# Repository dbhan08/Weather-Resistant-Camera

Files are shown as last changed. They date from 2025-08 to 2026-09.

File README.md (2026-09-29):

# Weather-Resistant Camera

An STM32-based enclosure that keeps a camera lens usable in rain and frost.
A vision model on the host PC (or, with the TFLite Micro path, on the MCU)
detects water on the lens and triggers a servo wiper; an on-die thermistor
turns a heating pad on below a threshold.  UIUC ECE 445 senior design,
Spring 2025.

## Run it

```bash
# firmware: open Final.ioc in STM32CubeIDE, build main.c, flash the Nucleo-F4
# vision (original OpenCV heuristic):
python final_code.py               # webcam -> HSV mask -> % coverage -> "START" over serial
# vision (CNN, see CNN/README.md):
python -m lens_soiling.infer runs/procedural/soilnet.pt --camera 1 --port COM3
```

## How it works

- **Firmware (`main.c`).**  TIM2 PWM drives the servo; `Set_Servo_Angle`
  maps 0–180° to a 210–1050 tick pulse.  ADC1 reads the internal temperature
  sensor with the factory `TS_CAL1/2` calibration, and drives a MOSFET on PA5
  to switch the heater.  USART2 at 115200 baud accepts 5-byte commands
  (`START`, `STOPP`) from the PC; `START` sweeps the wiper 60→115→60°.
- **Vision, heuristic (`final_code.py`).**  HSV threshold on low saturation
  and high value, morphological close, contours, enclosing circles, then
  percent of masked pixels.  Over 5 % sends `START`.
- **Vision, CNN (`CNN/`).**  Tile-level classifier: a ported pretrained
  raindrop CNN distilled into a ~20 k-parameter int8 model for TFLite Micro,
  plus a tested PyTorch fallback trained on synthetic drops and frost.
- **Hardware.**  KiCad PCB (`PCB Design*/`), 5 V and 3.3 V regulators, MOSFET
  heater switch, logic-level shifter, servo header.  Demo ran on the Nucleo
  dev board after the second PCB's MCU was damaged during hand soldering.

## Layout

```
main.c, Final.ioc          STM32 firmware and CubeMX project
final_code.py              OpenCV heuristic + serial trigger (PC)
python_to_stm_comm.py      serial protocol smoke test
CNN/                       CNN detection: pretrained port + from-scratch pipeline
Servo Motor code/, Temperature sensor code/   subsystem test firmware
PCB Design*/               KiCad
Lab Notebooks/             per-member design logs
```

## Stack

C (STM32 HAL), Python, OpenCV, PyTorch, TensorFlow Lite Micro, KiCad.

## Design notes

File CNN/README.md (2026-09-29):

# Rain detection CNN for the camera lens

The vision subsystem is a tile-level raindrop classifier that runs on the
STM32 under TensorFlow Lite Micro.  The MCU captures a 160x120 frame over
DCMI, classifies each 48 px tile with an int8 CNN, and triggers the wiper
when the fraction of raindrop tiles passes 5 %.  It replaces the PC-side HSV
threshold + contour heuristic in `../final_code.py`, which false-fired on
glare and surface texture (lab notebook, 2025-03-07 and 2025-04-05).

| Path | Folder | What it is |
|---|---|---|
| **Deployed** | `pretrained/` + `pretrained/tflm/` | Breckon's AlexNet-30² raindrop weights (ICIP 2018) → Keras port → fine-tune → distilled 20 k-param student → full-int8 TFLite → C array → TFLite Micro firmware |
| Fallback / experiments | `lens_soiling/` | PyTorch net trained on synthetic drops and frost; `pytest tests` passes |

## Pretrained path: how it works

1. **Port the weights (`port_breckon.py`).**  The published model is a
   TFLearn checkpoint from TensorFlow 1.x.  TF1 and TFLearn do not install on
   current Python or Apple Silicon, and the TFLite converter cannot read a
   `.tfl`.  But TF2's `tf.train.load_checkpoint` still reads TF1 variables,
   so the script rebuilds the exact graph in Keras and copies each tensor
   by name (`Conv2D`, `Conv2D_1`, ... `FullyConnected_2`).  Every shape is
   asserted, and the repo's 16 sample patches are re-classified so the port
   can be checked before anything else runs.
   Architecture: five convs (96·11×11/4, 256·5×5, 384·3×3, 384·3×3,
   256·3×3) with 3×3/2 max-pools and local response normalization, then
   4096-tanh, 4096-tanh, 2-softmax.  Input is a 30×30 RGB patch scaled to
   [0, 1].  The paper reports 0.95 accuracy on windshield-camera patches.
2. **Get labelled patches (`data_windshield.py`).**  RaindropsOnWindshield
   (8,190 frames, 3,390 with drops, pixel masks, CC BY 4.0) is cut into
   30×30 patches: positive if the mask covers ≥ 30 % of the patch, negative
   only if the patch *and a one-patch margin* are mask-free.  Splits are by
   video sequence so frames from one clip never leak across train / test.
3. **Fine-tune (`finetune.py`).**  Breckon's camera looked through a
   windshield.  Ours sits millimetres from the drops, so drops are bigger and
   blurrier.  Standard two-stage transfer: head only at lr 1e-3, then all
   layers at 1e-5 with early stopping.  Flips and ±45° rotation, as in the
   paper.
4. **Distill to an MCU-sized student (`distill_student.py`).**  After three
   pools a 30×30 input is 1×1×256, then 256×4096 and 4096×4096 dense layers:
   about 18 M parameters, 75 MB fp32, 19 MB int8.  The STM32F4 Nucleo has
   512 KB flash and 192 KB SRAM, and TFLite Micro has no LRN kernel.  So the
   teacher stays on the PC and a 48×48 depthwise-separable student
   (~20 k params, only CONV_2D / DEPTHWISE_CONV_2D / MEAN / FULLY_CONNECTED)
   is trained on the teacher's softened probabilities (Hinton et al. 2015,
   T = 4, α = 0.7) plus the hard labels.
5. **Quantize and emit C (`to_tflite.py`).**  Full-integer int8 with a
   representative dataset of validation patches, int8 in/out, then a
   `g_raindrop_student[]` C array.  The report records op list, byte size, input
   scale/zero-point, and int8-vs-fp32 argmax agreement.
6. **Run on the board (`tflm/`).**  `raindrop_inference.cc` sets up
   `MicroInterpreter` with a six-op resolver and a 48 KB arena, quantizes
   each tile with the converter's scale/zero-point, and returns the fraction
   of tiles classed raindrop.  `main_hook.c` shows the change to `main.c`:
   the servo sweep triggers on coverage ≥ 5 % with a 4 s cooldown instead
   of on a UART `START`.

```bash
# in a venv with tensorflow>=2.10, pillow, numpy
bash raindrop-detection-cnn/download-models.sh            # Breckon weights (MIT)
python -m pretrained.port_breckon models/alexnet_30_2_classification.tfl --out runs/breckon --samples raindrop-detection-cnn/images/classification
zenodo_get https://zenodo.org/record/4680442 --output-dir data/RaindropsOnWindshield
python -m pretrained.data_windshield data/RaindropsOnWindshield --out data/patches
python -m pretrained.finetune runs/breckon/alexnet30_2.keras data/patches --out runs/breckon_ft
python -m pretrained.distill_student runs/breckon_ft/alexnet30_2_ft.keras data/patches --out runs/student
python -m pretrained.to_tflite runs/student/student.keras data/patches/val --out runs/tflite --name raindrop_student
```

### Why not ship the pretrained model as-is

- It is 18 M parameters.  Too big for any STM32 by two orders of magnitude.
- It uses LRN, which TFLite Micro does not implement.
- It was trained on a windshield view, not a lens millimetres from the water.
- It has no ice class.  Ice is left to the thermistor, which the firmware
  already does.  A frost class can be added to the student later from the
  synthetic frost renderer in `lens_soiling/synth.py` or from real frames.

## From-scratch path (tested)

`lens_soiling/` is a PyTorch pipeline that renders adherent drops (minified,
inverted, blurred scene with a dark rim and specular highlight) and frost
(blur, desaturation, lift to white, fractal crystal texture) onto clean
tiles, trains a 19.7 k-parameter net, quantizes it to int8 and dumps a C
weight header.  On procedural backgrounds it reaches 98.5 % validation
accuracy with 100 % int8/fp32 argmax agreement.  That number is synthetic
and must not be quoted as real-world accuracy.

```bash
pip install -r requirements.txt
python -m pytest tests -q
python -m lens_soiling.train --epochs 8 --out runs/procedural
python -m lens_soiling.export runs/procedural/soilnet.pt --out runs/procedural
python -m lens_soiling.infer runs/procedural/soilnet.pt --image test.jpg
```

## Firmware

`pretrained/tflm/` holds the on-MCU side: `raindrop_inference.cc` (TFLM
interpreter, 6-op resolver, 48 KB arena, per-tile int8 quantization, DWT
cycle timing), `camera_dcmi.c` (OV7670 QQVGA RGB565 over DCMI + DMA),
and `main_raindrop.c`, the full main loop: thermistor → heater MOSFET,
capture → CNN → coverage → servo sweep, one status line per second over
USART2 with coverage, tile grid and inference microseconds.  Build steps
and the SRAM budget are in `pretrained/tflm/README.md`.

## Numbers

Record them from the USART2 status line (`nn_us`, `cover`, `grid`) and
from `export_report.json` / `tflite_report.json`.  Fill this table from
your own logs; do not copy synthetic numbers here.

| Metric | Value | Source |
|---|---|---|
| Student params / int8 model bytes | | `tflite_report.json` |
| int8 vs fp32 argmax agreement | | `tflite_report.json` |
| Test accuracy on held-out lens patches | | `distill_report.json` |
| On-MCU latency per 3x2 tile frame | | `nn_us` in the USART2 log |
| Tensor arena used | | `arena_used_bytes()` |

## References

- Guo, Akcay, Adey, Breckon. *On the impact of varying region proposal strategies for raindrop detection and classification using CNNs.* ICIP 2018. Code + weights: https://github.com/tobybreckon/raindrop-detection-cnn
- Soboleva, Shipitko. *Raindrops on Windshield: Dataset and Lightweight Gradient-Based Detection Algorithm.* 2021. https://github.com/EvoCargo/RaindropsOnWindshield
- Uřičář et al. *SoilingNet*, ITSC 2019; Das et al. *TiledSoilingNet*, 2020 (tile-level coverage idea).
- Qian et al. *Attentive GAN for Raindrop Removal*, CVPR 2018; You et al. *Adherent Raindrop Modeling*, TPAMI 2016 (drop appearance model).
- Hinton, Vinyals, Dean. *Distilling the Knowledge in a Neural Network.* 2015.
- Howard et al. *MobileNets.* 2017.

## Stack

Python, TensorFlow / Keras, TensorFlow Lite Micro, PyTorch, NumPy, Pillow, pytest, C/C++ on STM32 HAL.

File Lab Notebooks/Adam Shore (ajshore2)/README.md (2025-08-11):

# 2025-02-12 - Project Proposal
After working on the project proposal, I believe we have a good idea. It is complex enough to challenge us, while also being within the scope of the class. Me and my group worked to complete our proposal this week. I was mostly responsible for the high-level requirements, visual aid, ethics, and safety sections. Beyond this, I helped contribute to each of the other sections as well. 

# 2025-02-18 - Discussion with Professor Fliflet
Professor Fliflet helped us brainstorm many other helpful ideas that will allow us to better complete our project. First, we will add in an LED to the heating system so it is easier for the user to identify when the heating component is activated. This also will make debugging easier. Additionally, we decided to not use hydrophobic spray. This would make our project much harder and put much more stress on the machine shop. This should allow us to better focus on our primary goals for the project.

# 2025-02-24 - Researching Parts
I have been looking into various different components to use for a variety of subsystems on the project. Primarily with the temperature sensor, it is difficult to find one that is easy to use and is waterproof (as to not break from rain). Temporarily I have settled on the temperature sensor listed below since it follows these requirements and appears to be user friendly.

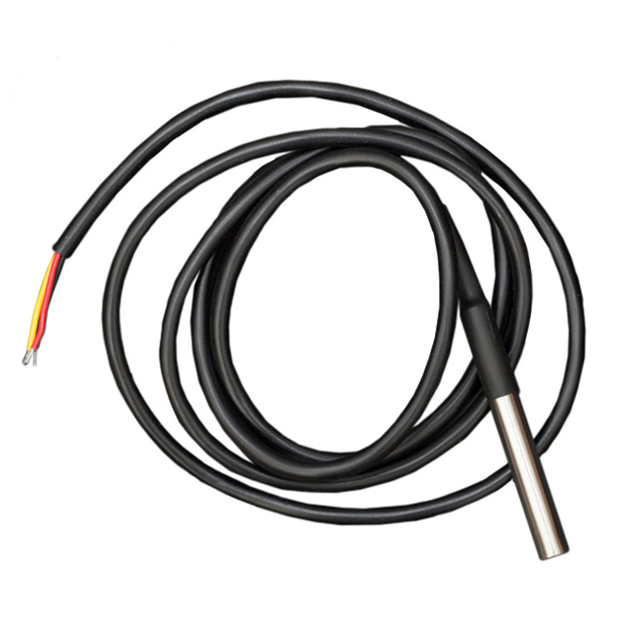
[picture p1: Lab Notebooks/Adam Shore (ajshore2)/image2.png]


[Link to Temperature Sensor](https://www.digikey.com/en/products/detail/dfrobot/DFR0198/7597054)

Additionally, we have been reviewing and evaluating which microcontroller is best suited for our project. We have temporarily decided to go with an STM32 microcontroller since it has many online resources to help us interact with it. Additionally, the ECE445 website has a wiki page which we find very helpful in learning about using this microcontroller. 

[Link to STM32 Microcontroller](https://www.digikey.com/en/products/detail/stmicroelectronics/STM32F103C8T6/1646338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)

After meeting with my team, we have also decided to not use any humidity sensor. We think it will be very difficult to incorporate this into our design since it would complicate the schematics greatly and possibly cause blockage of the camera. We will try to revisit this and add it to our project later if there is time at the end. However, we believe our project can still function effectively without this. 

# 2025-02-27 - First PCB
Since we do not think our first PCB is ready to order yet, we are going to spend more time on it and ensure it will work before ordering. This means we will be placing our first PCB order in the second-round orders. So far, we have constructed a PCB that has a majority of the components we need, however, we need to add any necessary resistors and capacitors for these components, as well as research any additional components we may need. 

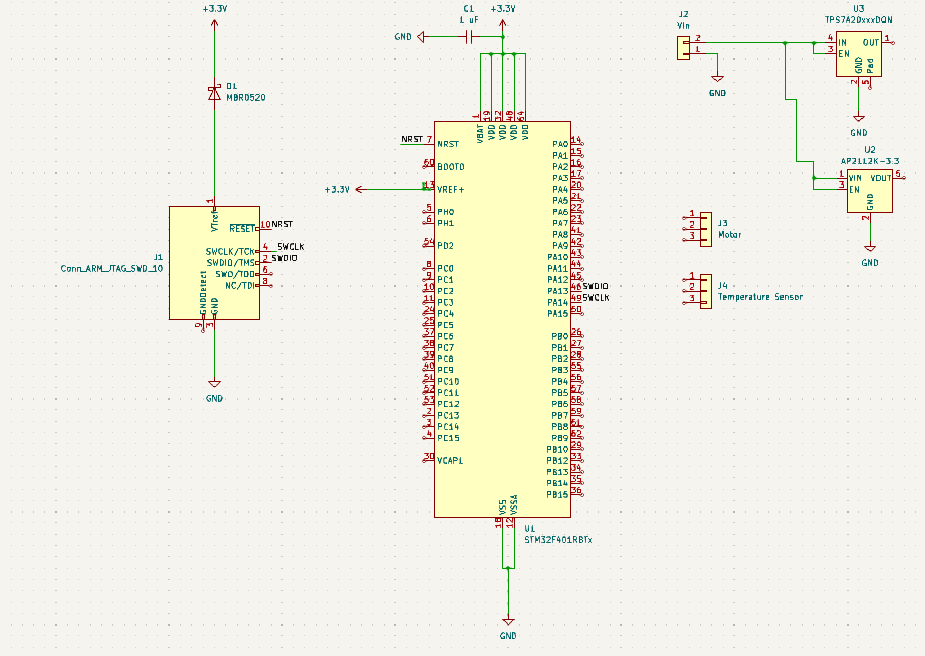
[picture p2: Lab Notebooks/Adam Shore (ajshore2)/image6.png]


# 2025-03-01 - First PCB (Continued)
We have added multiple other components to our PCB. This includes a receiver to communicate with the computer in the form of a USB-C 2.0 port. Additionally, we added a component to plug the heater into. Finally, we added another voltage regulator in order to power the heater, which we realized needs 5 V to power. 

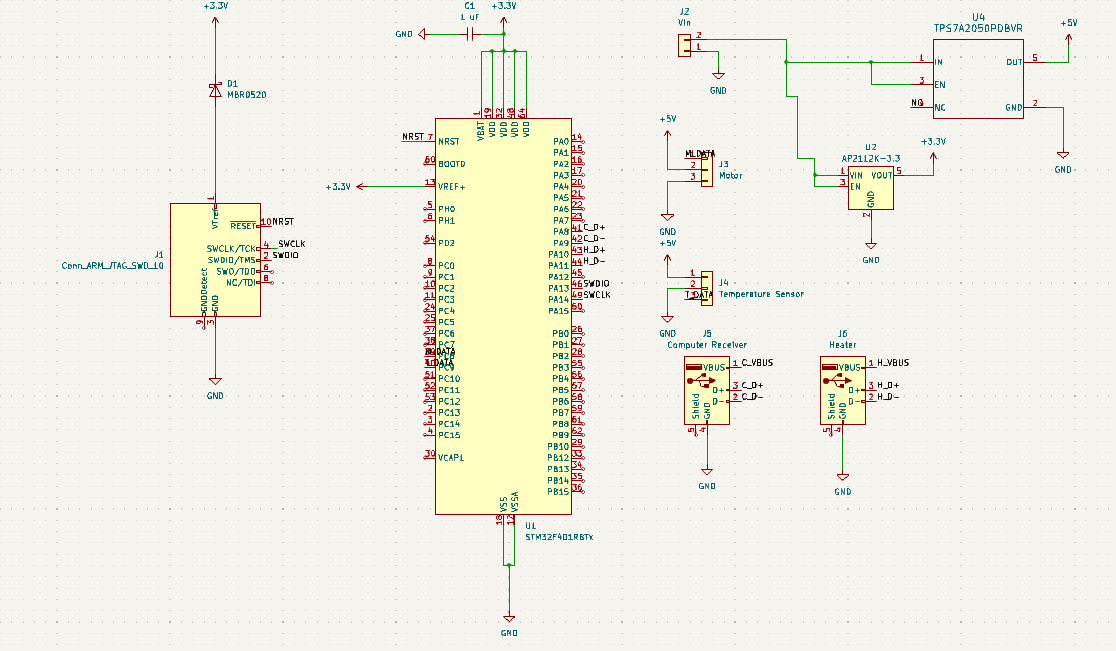
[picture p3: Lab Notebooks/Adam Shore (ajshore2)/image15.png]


# 2025-03-05 - Design Document
Me and my group spent lots of time working on our design document this week. We want to make sure we are thorough with our work so that we can effectively build and test our project later. While my group members and I all played a role in each section, I was primarily responsible for the following sections: cost, schedule, high-level-requirements, visual aid, ethics, safety, and citations. 

# 2025-03-06 - First PCB (Continued)
I have continued working on our PCB design and believe we are now at a point where we can place our order. We have added a MOSFET which will allow for the heater to properly run. We have also added a spot for the LED light, the debug header, the timing crystals, and more. Additionally, we added many more resistors and capacitors which we needed in our design.

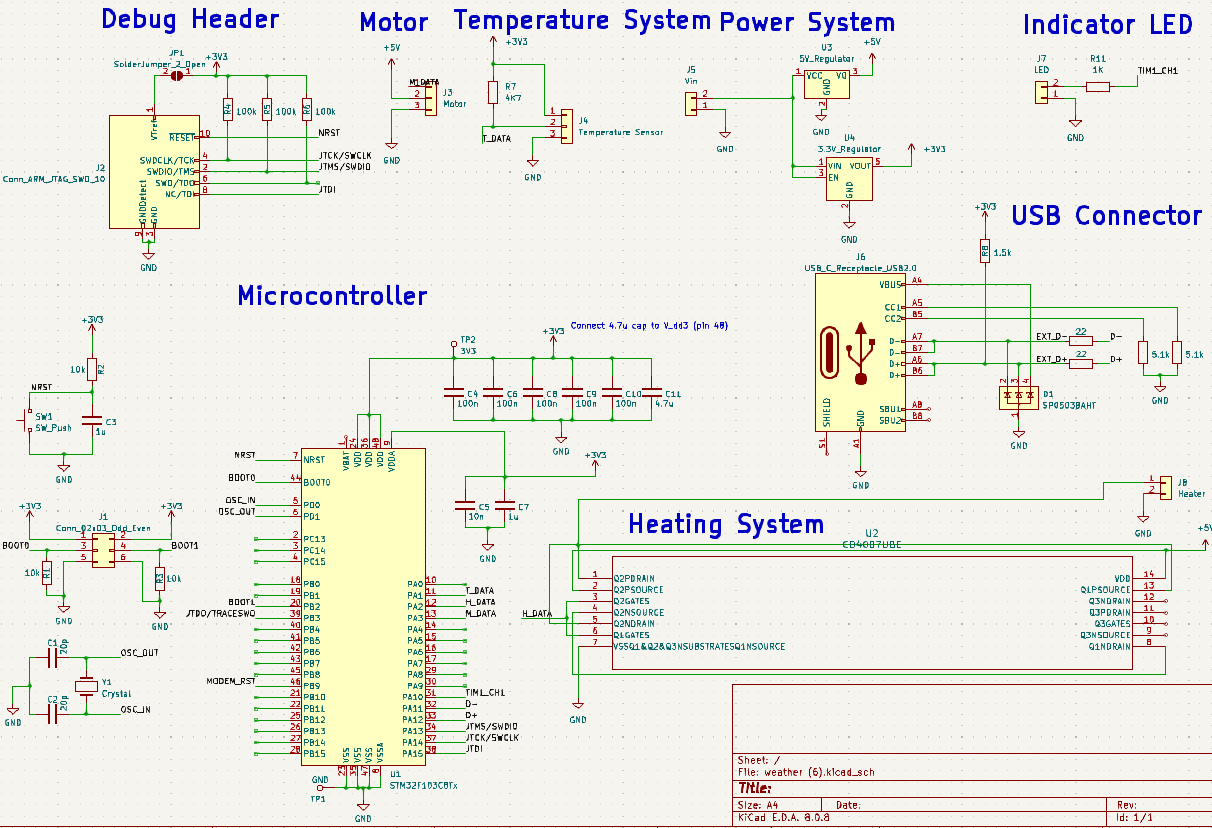
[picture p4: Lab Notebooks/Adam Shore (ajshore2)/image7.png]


# 2025-03-07 - Temperature Sensor Readings
I have been working with our temperature sensor (DFR0198) and our development board in order to try to get proper readings with the device. Unfortunately, I am continuously getting errors reading from the device. I am able to properly communicate a “reading” from the microcontroller to my computer for me to visualize using UART and displaying it with Putty. However, the readings are coming in as gibberish characters, meaning there is either a problem with the data line, the temperature sensor itself, or how I am reading it. 

# 2025-03-08 - Breadboard Assembly
My group has tried to begin assembling the parts together utilizing our development board, in order to have some subsystems working in time for the breadboard demo. Currently we plan to show the temperature sensor readings (even though they are incorrect), the PWM generation from our development board, and our CNN model. 

# 2025-03-13 - Temperature Sensor Readings (Continued)
Since I am unable to get proper readings using the DFR0198 temperature sensor, I have attempted to get readings using the on-board temperature sensor. This has worked and we will be using this method going forward. Once the PCB is working, I plan to revisit the temperature sensor issue and try once again to obtain correct readings. 

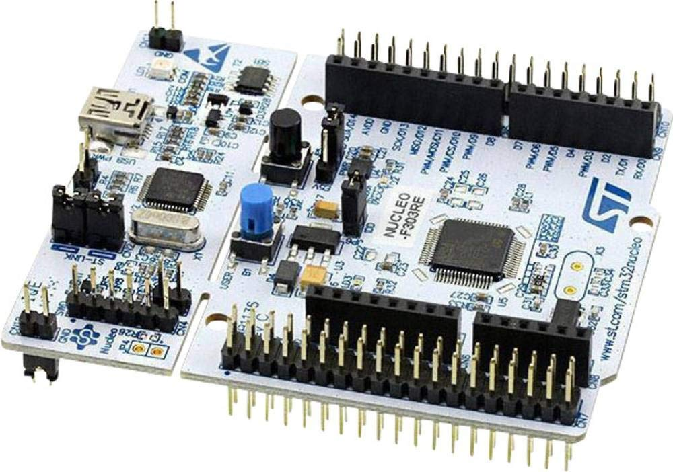
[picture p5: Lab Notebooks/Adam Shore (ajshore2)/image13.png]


[Link to STM32 Development Board & Image](https://www.amazon.com/Nucleo-64-development-STM32F303RE-supports-connectivity/dp/B01N6EKDEF)

In order to verify my results, I conducted 20 trials where I read the temperature from the development board and compared it to the actual temperature. I did this by testing a few various environments which slowly became colder. I waited for the temperature sensor to adjust and then compared this to the thermometer readings. After the following results, I concluded that it was accurate.

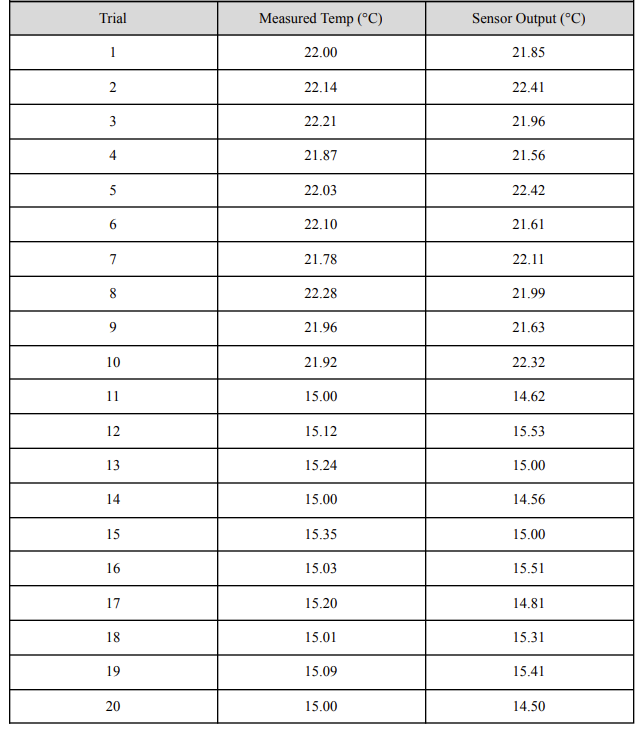
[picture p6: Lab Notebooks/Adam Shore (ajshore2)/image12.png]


# 2025-03-25 - First PCB Assembly
We have begun soldering our first PCB. We are attempting to solder it in subsystems in an attempt to unit test each subsystem. Some of our subsystems we have soldering and verified work, such as the power subsystem. We know certain parts of our PCB will not work because we realized mistakes we had made after ordering it. This came in various forms such as forgetting pull-up resistors in certain areas, utilizing the incorrect components, and more. Because of this, we were not able to solder and test everything. 

# 2025-04-03 - Second PCB
After noting errors that prevented us from being able to effectively assemble and test our PCB, we started creating our next PCB which revised these errors. We corrected the MOSFET circuit, the temperature sensor circuit, and more. We plan to finalize these changes and order the PCB as soon as possible. 

# 2025-04-08 - Breadboard Assembly
In case our PCB still fails we are attempting to assemble everything together utilizing the development board and a breadboard. I have begun programming the microcontroller to trigger the heater and motor based on the temperature sensor readings. I am also practicing various ways to use python to trigger a high pin output on the board. This is important because we need the OpenCV model to be able to trigger the motor physically. I am attempting to do this communication through UART and the TX/RX pins. Below is the microcontroller code I have so far in order for the temperature to trigger the heater:

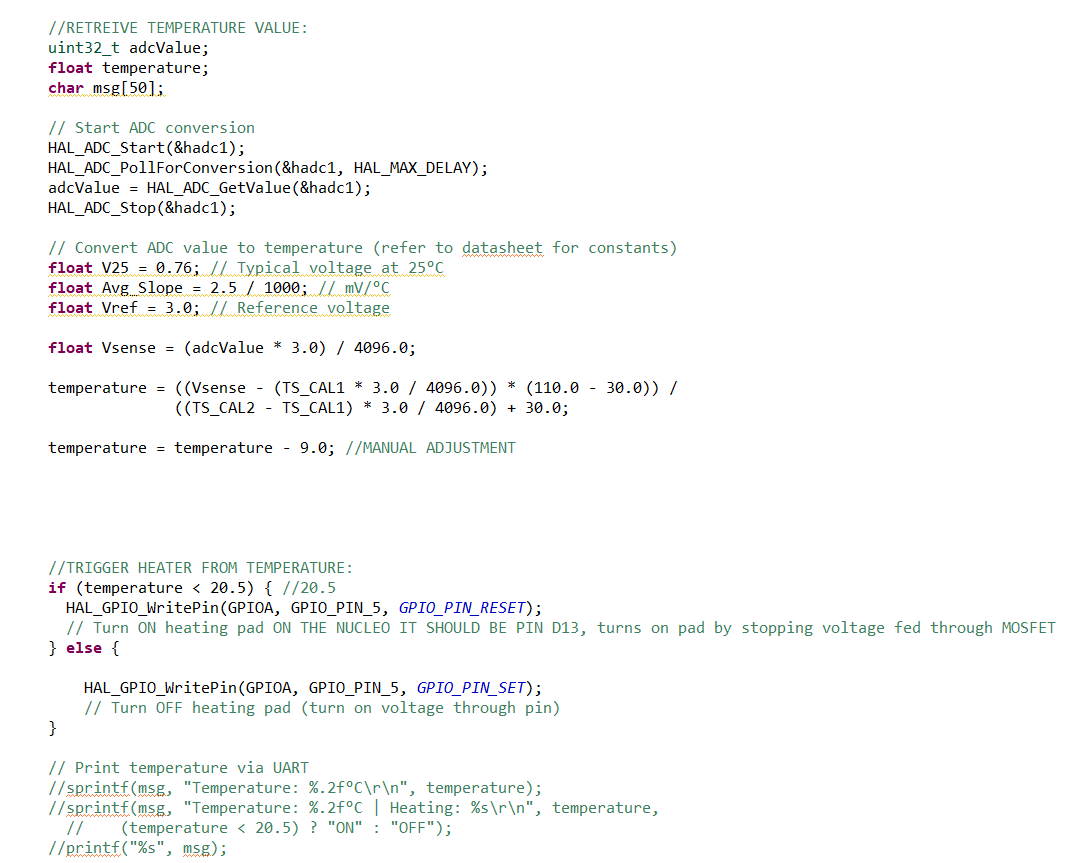
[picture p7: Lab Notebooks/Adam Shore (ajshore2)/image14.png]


# 2025-04-10 - Breadboard Assembly (Continued)
I have been able to find a way to communicate from Python to the Development board in order to have the OpenCV model directly trigger the motor. Here is the code I am using to do this: 

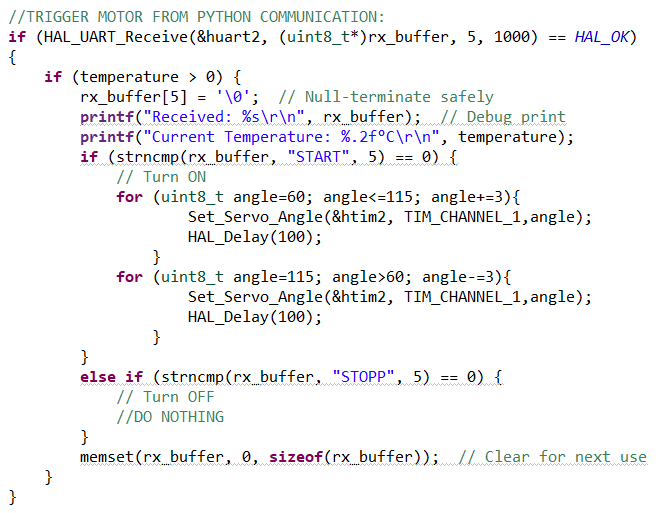
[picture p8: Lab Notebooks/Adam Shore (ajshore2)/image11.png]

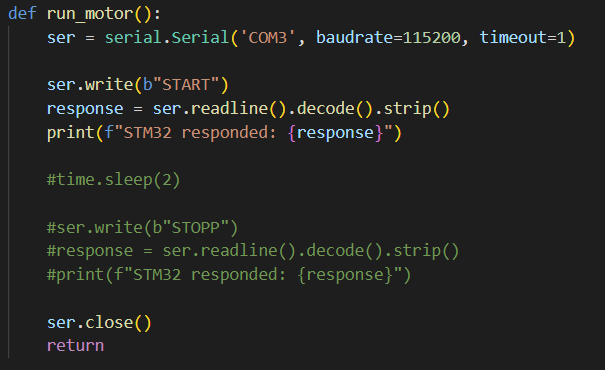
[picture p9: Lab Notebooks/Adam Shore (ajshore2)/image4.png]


# 2025-04-23 - Second PCB Assembly
When assembling our second PCB, we broke our microcontroller. Unfortunately, we were not able to solder the microcontroller due to the intricacies of its parts. We are going to try and order another one in time and attempt to solder it again, however, we are also going to shift our focus to making sure our final project works on the development board in order to ensure we have a final working product.

# 2025-04-25 - Final Demo Preparation
My group now has our final project working on our development board. We are able to trigger various subsystems from other subsystems. We are now going to start practicing what we want to show for our final demo so that we are prepared to showcase both our end-to-end functionality along with our subsystems verifications. We are using a cooler filled with ice in order to imitate a freezing environment, however, this does not replicate a perfect freezing temperature. In order to adjust for this, we will simulate our conditions where 20 degrees Celsius is our threshold for freezing, instead of 0 degrees Celsius. Below is our final layout of our microcontroller:

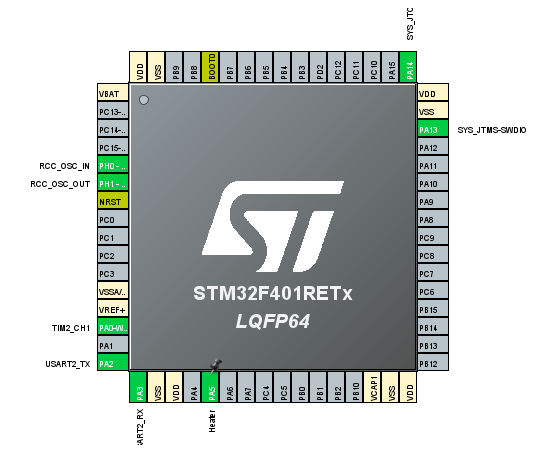
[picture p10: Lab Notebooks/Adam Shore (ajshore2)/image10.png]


Below I have attached images of our final product constructed all together so it can be visualized easier:

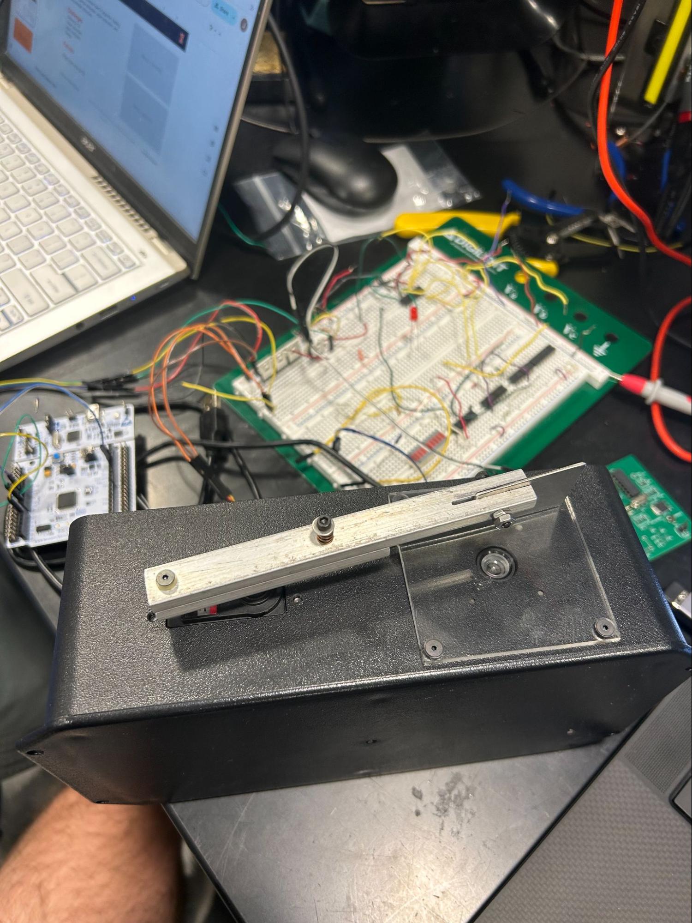
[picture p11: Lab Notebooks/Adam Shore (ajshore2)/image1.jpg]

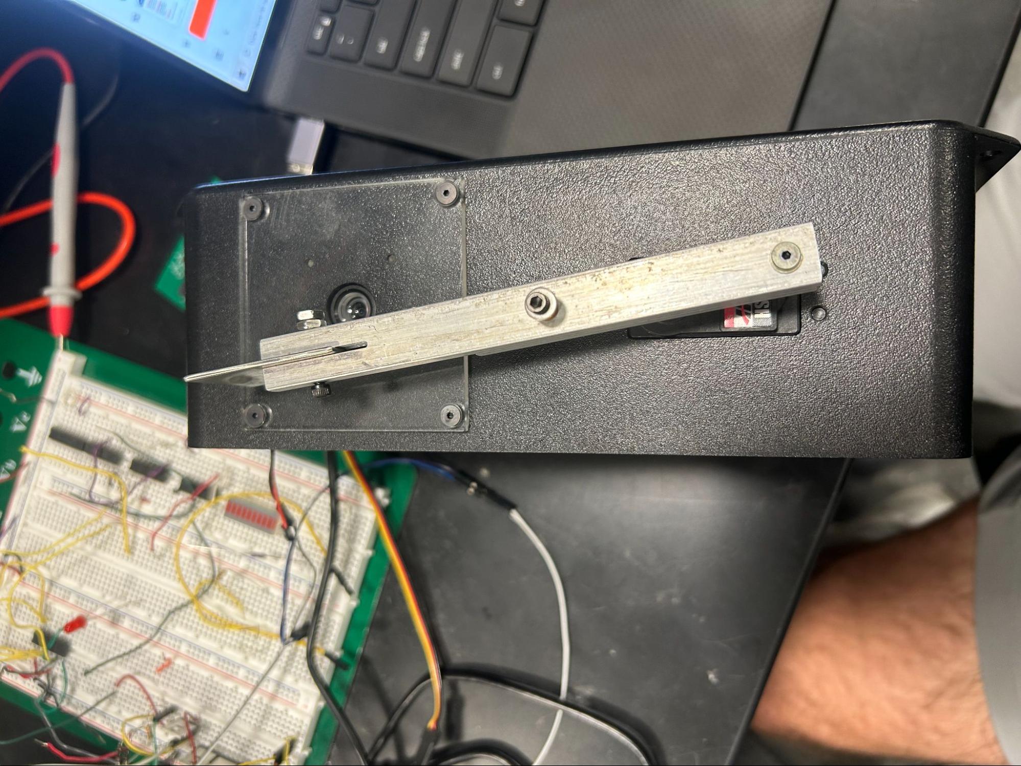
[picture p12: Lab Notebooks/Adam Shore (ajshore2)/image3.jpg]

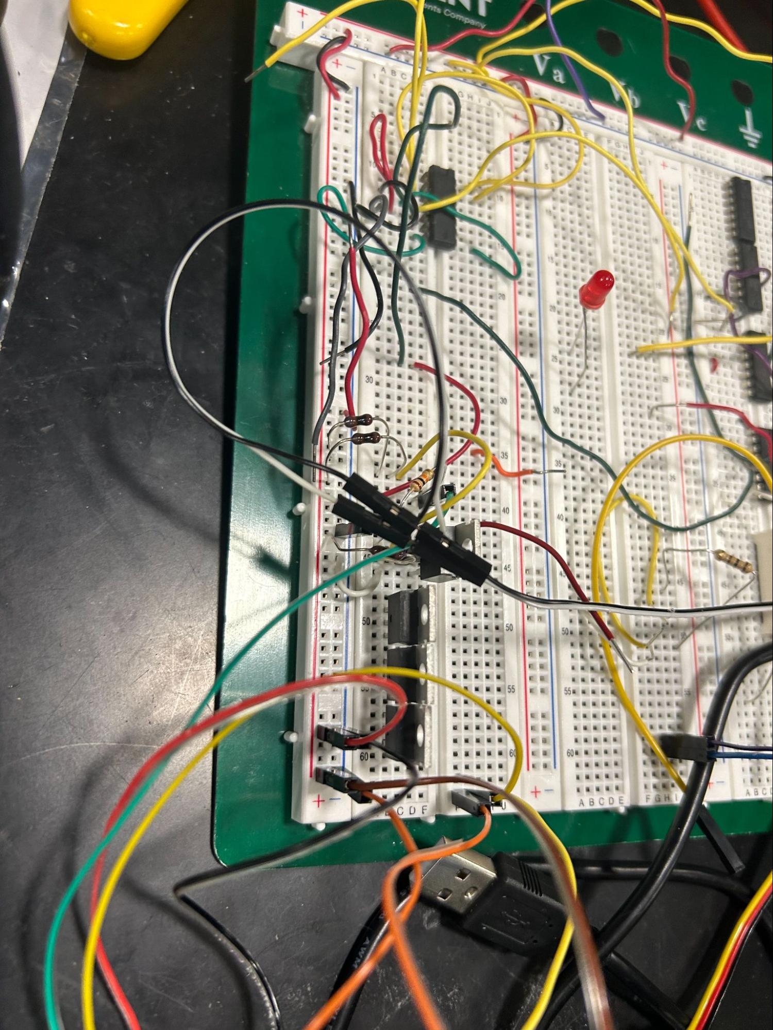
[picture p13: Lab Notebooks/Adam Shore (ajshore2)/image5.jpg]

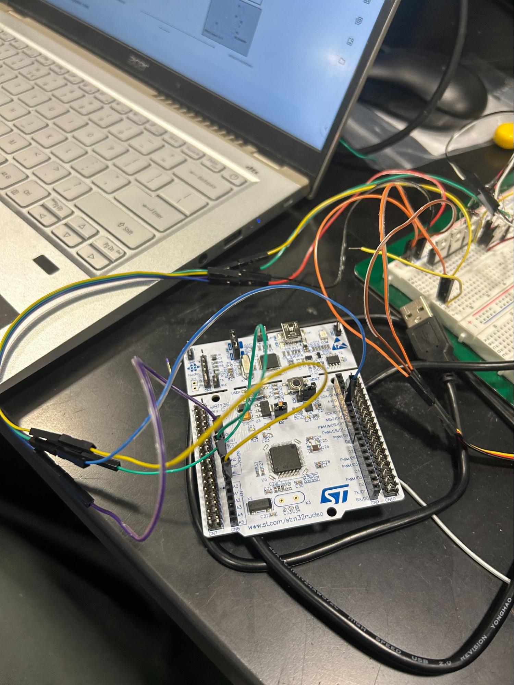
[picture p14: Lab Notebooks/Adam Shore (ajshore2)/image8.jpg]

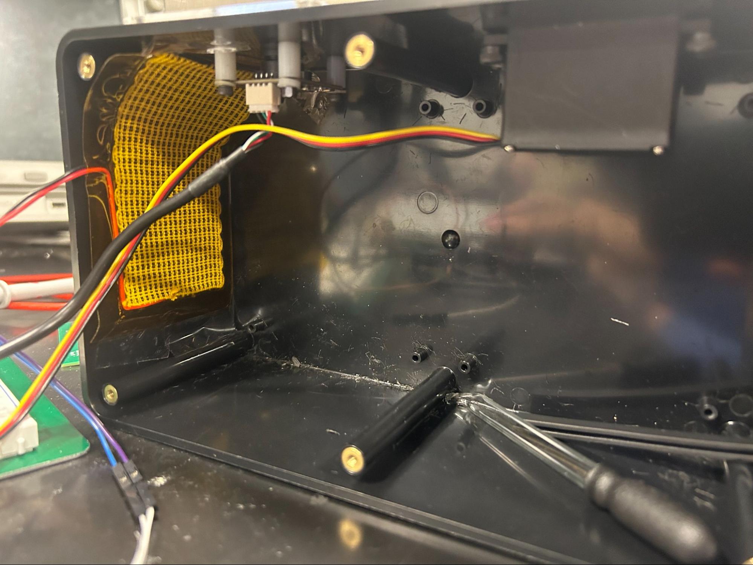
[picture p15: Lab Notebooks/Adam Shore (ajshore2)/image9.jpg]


# 2025-04-30 - Final Presentation Preparation
Our final demo went great and we were able to successfully showcase full end-to-end functionality. We are now diverting our attention to the final presentation where I am practicing what to say for my slides, along with making sure my slides communicate all of the necessary information. 

# 2025-05-07 - Recap
The final presentation went very well and I think my group did a great job communicating our information and results. I am very proud of all of the work I have put into this project all semester and I am excited to use this experience in the future. 

# Additional References

[1] 	IEEE, “IEEE Citation Guidelines,” IEEE Dataport, [Online]. Available: https://ieee-dataport.org/ 
sites/default/files/analysis/27/IEEE%20Citation%20Guidelines.pdf. [Accessed: Feb. 12, 2025].
 
[2]	HS-318 Servo-Stock Rotation, “HS-318 Servo-Stock Rotation,” ServoCity®, 2025. 
https://www.servocity.com/hs-318-servo/. [Accessed: Mar. 6, 2025].
 
[3]	“0.3 MegaPixels USB Camera for Raspberry Pi and NVIDIA Jetson Nano 
SKU:FIT0701.” Available: https://mm.digikey.com/Volume0/opasdata/d220001/medias/docus/ 
2719/FIT0701_Web.pdf. [Accessed: Mar. 6, 2025].
 
‌[4]	“Waterproof DS18B20 Digital Temperature Sensor for Arduino.” Accessed: Mar. 06,      
2025. [Online]. Available: https://mm.digikey.com/Volume0/opasdata/d220001/medias/docus/ 3786/DFR0198_Web.pdf. [Accessed: Mar. 6, 2025].
 
[5]	“NUCLEO-F401RE - STM32 Nucleo-64 development board with STM32F401RE MCU, 
supports Arduino and ST morpho connectivity - STMicroelectronics,” www.st.com. https://www.st.com/en/evaluation-tools/nucleo-f401re.html. [Accessed: Mar. 6, 2025].
 
‌[6]	“Heating Pad -5x10cm.” Accessed: Mar. 06, 2025. [Online]. Available: https://mm.digikey.com/ 
Volume0/opasdata/d220001/medias/docus/2511/COM-11288_Web.pdf. [Accessed: Mar. 6, 2025].
 
[7]	“STM32F103C8 - STMicroelectronics,” STMicroelectronics, 2019. https://www.st.com/en/ 
microcontrollers-microprocessors/stm32f103c8.html. [Accessed: Mar. 6, 2025].
 
‌[8]	Engineering IT Shared Services, “:: ECE 445 - Senior Design Laboratory,” Illinois.edu, 
2025. https://courses.grainger.illinois.edu/ece445/wiki/#/stm32_example/index?id= stm32- example-lora-router. [Accessed: Mar. 6, 2025].
 
[9]	“Servo Motor Control with STM32 | EASY TUTORIAL | STM32CUBEIDE,”
Youtube, uploaded by CircuitGator HQ, 15 January 2025, https://www.youtube.com/watch?v=0aTMuiHVx_g. [Accessed: Apr. 2, 2025].

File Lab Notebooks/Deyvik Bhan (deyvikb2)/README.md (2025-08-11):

# **02-11-2025: Project Proposal**

Our group collaborated on the proposal for the weather-resistant camera project, working together to divide the system into seven core subsystems: the heater, sensor, microcontroller, wiper, power, computer, and camera. Early in the process, we held discussions to outline each subsystem's role and ensure that the overall design was cohesive. I contributed by writing the *Introduction* and *Proposed Solution* sections of the proposal, helping to clearly explain the motivation behind our project and the strategy we planned to use. Additionally, I worked on part of the *Subsystem Overview*, describing how the different components would function and interact to maintain clear camera visibility in adverse weather conditions.

# **02-14-2025: Initial Machine Shop Meeting**

Another group member and I brought our proposal to the machine shop, where we explained the functionality of our project and how the system was intended to operate. While there, Greg offered valuable input on the physical design, suggesting the use of protective boxes for housing components and helping us select appropriate servo motors. He also provided ideas for implementing the heating element, guiding us on possible materials and configurations that could effectively support our system’s de-icing capabilities.

# **02-18-2025: Proposal Review with Professor Fliflet**

During the proposal review, Professor Fliflet gave us several valuable ideas for implementation through his detailed questions. He prompted us to consider specific aspects such as the size of the enclosure box and where individual components—like the sensor, heating element, and wiper—should be placed for maximum efficiency. These questions helped us think more carefully about our layout and pushed us to refine the physical design of the system to ensure everything fits properly and functions as intended.

# **02-24-2025: Researching Parts**

As part of my contribution, I focused on researching potential camera modules for the system. After evaluating several options, I identified the DFRobot FIT0701 as a cost-effective and practical solution that aligns well with our project’s technical and budgetary requirements. It provides the necessary image quality without introducing unnecessary complexity. Additionally, during our discussions, we concluded that a humidity sensor would not be necessary for our application. As a group, we also agreed to use the STM32 microcontroller, as some team members have prior experience with it and it offers the capabilities we need to coordinate the different subsystems effectively.

[Link to Camera](https://www.digikey.com/en/products/detail/dfrobot/FIT0701/13166487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)
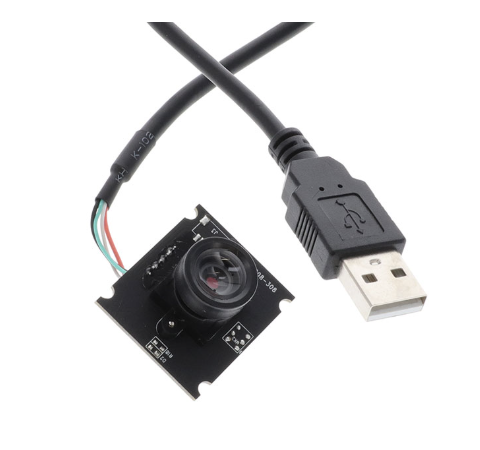
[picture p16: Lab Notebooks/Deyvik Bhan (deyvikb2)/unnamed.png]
# 

# **02-25-2025: First PCB**

Using the components we selected through our research, our group collaborated to begin designing the PCB. We have a general understanding of how most parts need to interface with the board—for example, we know that the motor will require three connectors. However, we’re still working out how to properly route the pins from the microcontroller to the other components on the board. Our PCB design so far is based on the structure and workflow we learned during the KiCad assignment. The current version of our layout is shown below.

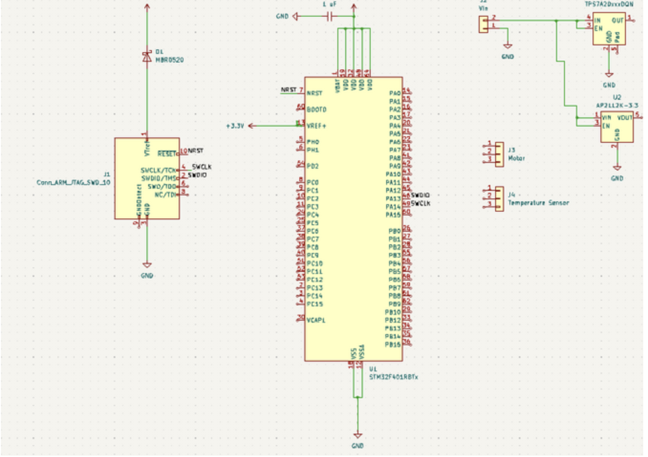
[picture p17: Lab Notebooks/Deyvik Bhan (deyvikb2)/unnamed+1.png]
# **02-27-2025: First PCB (Continued)**

Our group met during office hours to review our initial PCB design and received valuable guidance that led to several important updates. We realized we needed to add additional components, including a USB connector to support the computer and heater subsystems, as well as crystal oscillators to ensure proper timing functionality for the microcontroller. We also discovered that the 5V voltage regulator we had originally chosen was not appropriate for our system and replaced it with a more suitable option. These changes helped refine our design to better meet the needs of our subsystems. The updated PCB layout is shown below.
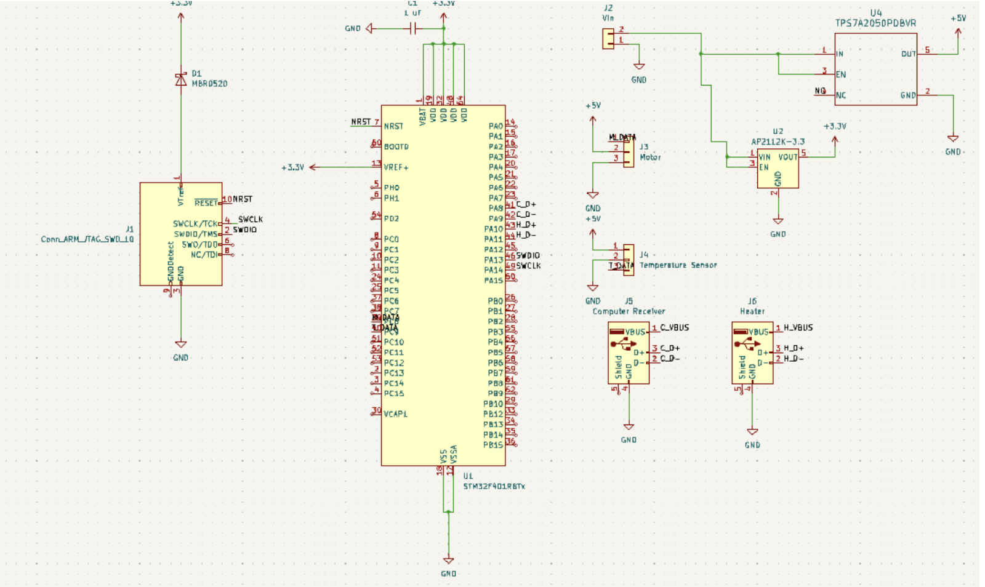
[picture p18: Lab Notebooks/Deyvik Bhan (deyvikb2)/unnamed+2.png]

# **2-28-2025: PCB Review**

During the PCB review, our group met with a TA who showed us a reference design for the STM32 microcontroller on the course website. This example became the foundation for our updated PCB layout, and we made several important adjustments based on it. One major change was switching the specific STM32 microcontroller we were using to better align with the example and ensure compatibility with our design.

We also decided to move away from using a heater that required a USB connection and instead selected one that only needed power and ground. To allow the microcontroller to control the heater, we incorporated a logic level shifter to convert the STM32’s 3.3V signal to the 5V required by the heater. Additionally, we added LEDs—particularly for the heater subsystem—to serve as visual indicators and aid in debugging.

These updates led us to significantly revamp our original PCB layout, and we now follow the STM32 reference design much more closely to ensure functionality and simplicity.

# **03-05-2025 : Design Document**

My group and I dedicated a significant amount of time this week to developing our design document. We aimed to be as thorough and detailed as possible to ensure a smooth path forward during the build and testing phases of our project. While all group members contributed across different sections, I was primarily responsible for writing the *Introduction*, *Problem Statement*, and *Proposed Solution*. I also contributed to parts of the *Design* section, specifically by helping write the *Subsystem Descriptions*, where we outlined the purpose and functionality of each major component in our system.

# **03-06-2025 : Continuing PCB Design**

As a group, we’ve continued refining our PCB design and now feel confident that it’s ready for ordering. Since the previous version, we’ve made several important additions, including a MOSFET to enable proper control of the heater, as well as spots for the LED indicator, debug header, timing crystals, and other key components. We also added additional resistors and capacitors that were necessary to support the circuit’s stability and functionality.

With the changes inspired by the STM32 example from the wiki page shown during the PCB review—and the integration of the MOSFET circuit—we arrived at our third iteration of the PCB design. This latest version reflects a more complete and robust layout, positioning us well for the next phase of the project.
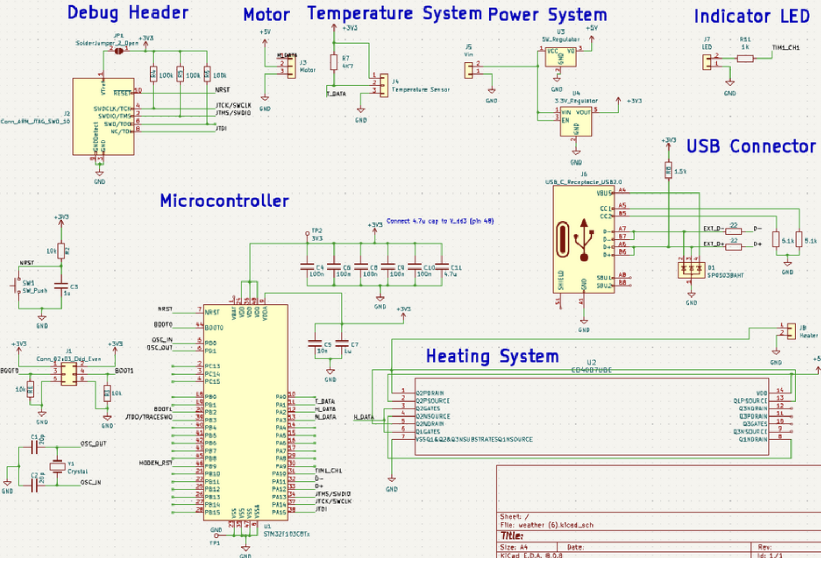
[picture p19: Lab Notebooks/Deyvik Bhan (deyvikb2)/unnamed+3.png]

In addition to our hardware progress, today I focused on the computer vision portion of the project. Using OpenCV, I was successfully able to interface with the selected camera and display a live video feed on the computer. This was an important step in validating the functionality of the camera subsystem and ensuring it integrates smoothly with the rest of our system.

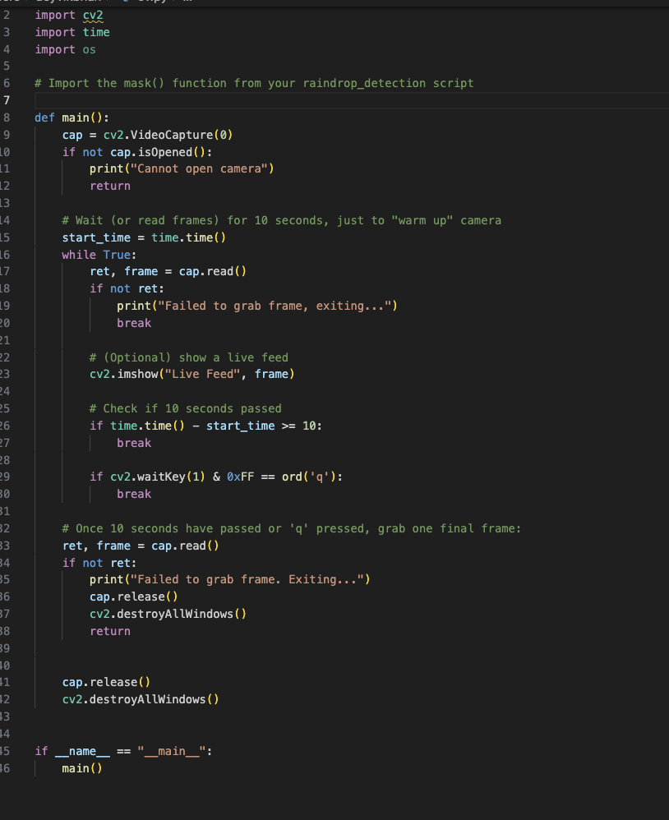
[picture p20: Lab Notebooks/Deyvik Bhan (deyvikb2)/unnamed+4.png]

# **03-07-2025 : OpenCV algorithm**

For the raindrop detection portion of the project, we initially attempted to use a convolutional neural network (CNN) for real-time detection. While the model performed reasonably well on its own, integrating it with the live camera feed introduced significant lag, making it too slow for real-time operation. As a result, we decided to switch to a purely OpenCV-based approach for detecting raindrop-like obstructions on the camera lens.

I’ve been actively working on developing and testing this OpenCV-based detection method. Using a range of test images, I’ve confirmed that the algorithm can identify potential raindrop patterns. However, we are still encountering a high number of false positives, where glare, lighting artifacts, or surface textures are mistakenly flagged as raindrops. I'm continuing to refine the detection logic to improve accuracy and reduce noise in the results ahead of the final demo.
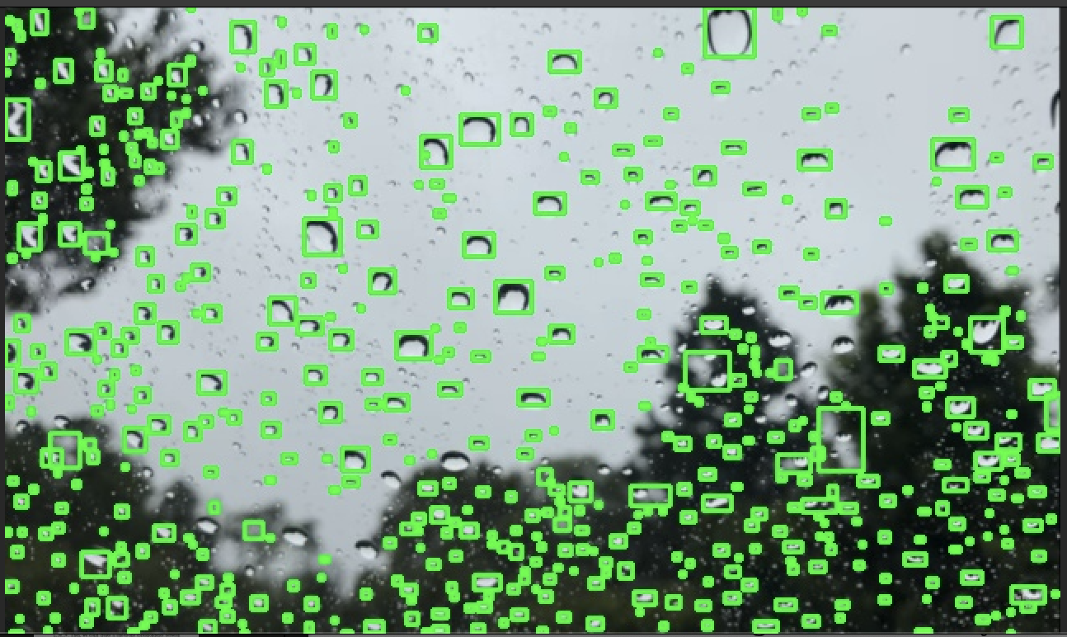
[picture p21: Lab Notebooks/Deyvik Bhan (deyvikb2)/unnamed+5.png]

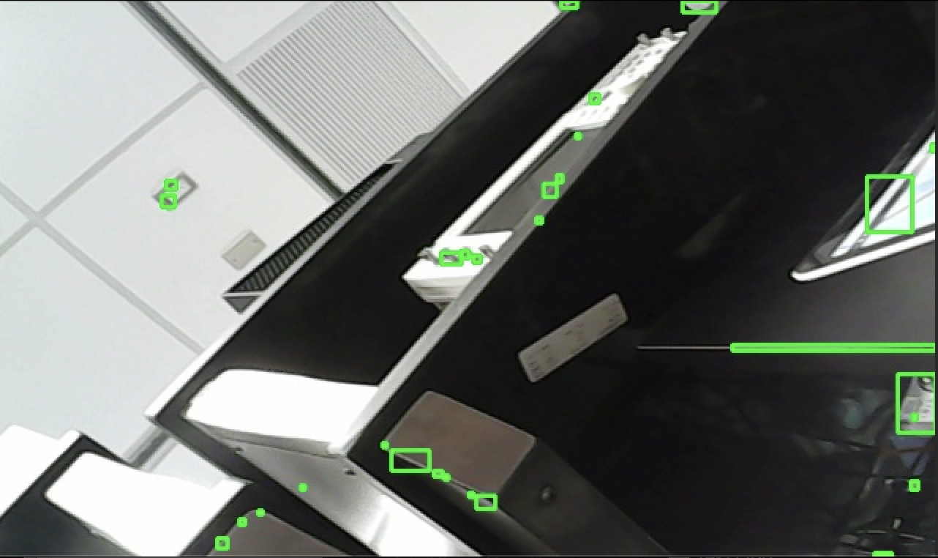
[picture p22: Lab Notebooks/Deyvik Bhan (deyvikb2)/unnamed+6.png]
# 

# **03-08-2025 : Breadboard Assembly**

To prepare for the upcoming breadboard demonstration, our group has begun integrating various components using the development board. The goal is to have a few key subsystems functioning to showcase our early progress. At this stage, we’re planning to present live temperature readings (though we’re still troubleshooting accuracy issues), demonstrate PWM signal output from the development board, and show the live camera feed using OpenCV with some rain drop detection. These demos will give us a chance to verify that our setup is on the right track and help us identify what still needs refinement moving forward

# **03-11-2025 : Breadboard Assembly**

We met today over Zoom to finalize the PCB wiring for our second-round submission. As a group, we worked together on placing the components, and another team member completed the remaining wiring. While all connections have been routed and there are no unrouted wires left, the design still does not pass the Design Rule Check (DRC), so we’ll need to make additional adjustments before it's ready to be sent

# **03-14-2025 : Machine Shop**

I visited the machine shop with another group member, where we spoke with Greg about the physical build of our project. He advised us to come back next time with a design based on a box he provided us during the visit. Greg also mentioned that our project wouldn’t take long to fabricate, so there was no need to submit anything to him before Spring Break.

# **03-25-2025 : Soldering the first PCB**

We’ve started soldering our first PCB, focusing on assembling it subsystem by subsystem so we can unit test each part individually. So far, we’ve successfully soldered and verified the power subsystem—both voltage regulators are functioning as expected, providing 5V and 3.3V outputs. The MOSFET circuit is also outputting 5V, which is consistent with the absence of a control signal from the microcontroller.

However, we’ve identified several design issues that are preventing us from fully soldering and testing the entire board. These include missing pull-up resistors in certain areas and a few incorrect component choices. Unfortunately, these errors were only discovered after the PCB had been ordered, so we’re working around them where possible and focusing on verifying the subsystems that are still testable.

# **03-31-2025 : Machine Shop**

We provided Greg with our updated design for the enclosure, and during our visit, he helped us test the servo motor using a servo tester. Through this, we confirmed that the motor was indeed broken, which helped us rule out wiring or code as the issue.

# **04-05-2025 : Working on OpenCV**

I’ve been actively working on refining the raindrop detection system to reduce the high number of false positives we’ve been encountering with the OpenCV-based approach. After running tests on a variety of images, I noticed that the algorithm often misidentifies glare, textures, or small distortions as raindrops. To address this, I’ve experimented with different filtering techniques and parameter tuning within the OpenCV pipeline.

I also met with our TA to troubleshoot the issue further. Through that discussion, we identified a key contributing factor: the mechanical setup of the camera places it too close to the surface where raindrops form. As a result, the camera is too zoomed in, which causes minor visual inconsistencies to appear more pronounced, leading to an increased rate of false detections. This insight has helped us better understand the limitations of our current hardware configuration and will inform future design adjustments.

# **04-12-2025 : Working on OpenCV (Continued)**

Over the past few weeks, I’ve been developing an OpenCV-based algorithm specifically tailored to work with our mechanical camera setup, where the lens is positioned very close to the surface where raindrops form. This proximity created challenges with image clarity and scale, but I was able to create a solution that effectively highlights the dark edges of raindrops, improving detection accuracy within our constrained setup.
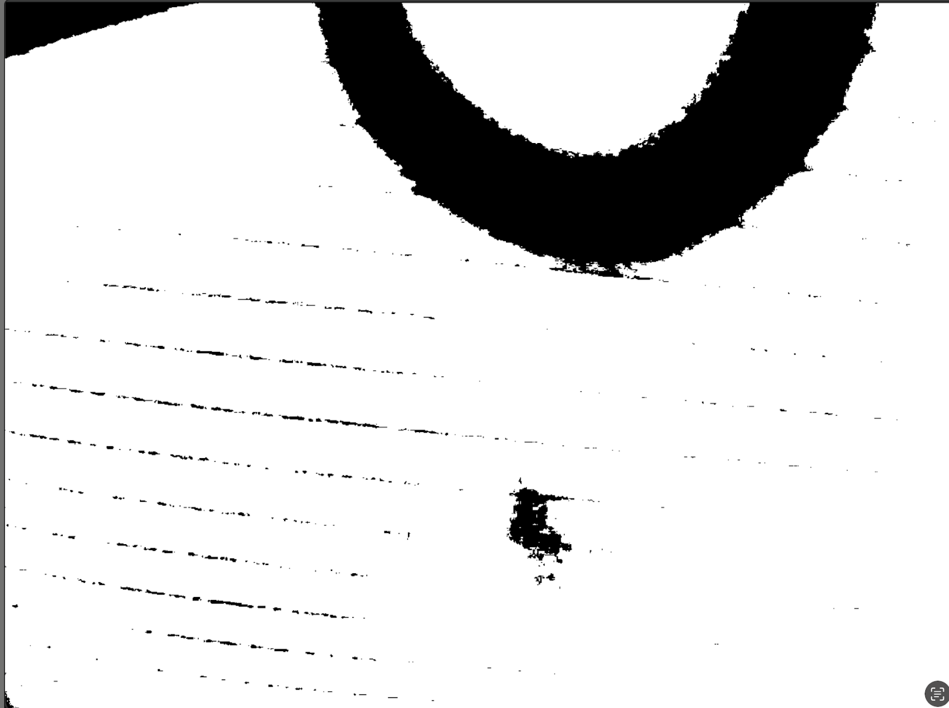
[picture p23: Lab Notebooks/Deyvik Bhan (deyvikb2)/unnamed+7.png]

# **04-14-2025 : Working on OpenCV (Continued)**

Building on the detection of dark raindrop edges, the next step in the algorithm involves enclosing these edge contours within circles to approximate the full shape of each raindrop. Once the circles are established, we can fill in the interior regions—initially containing lighter pixels—with black pixels. This allows us to better estimate the true coverage of the screen by raindrops, rather than relying solely on edge data. By filling in these regions, we can quantify the percentage of the camera view obstructed by raindrops more accurately, which can then be used to trigger responses from other subsystems such as the wiper or heater.
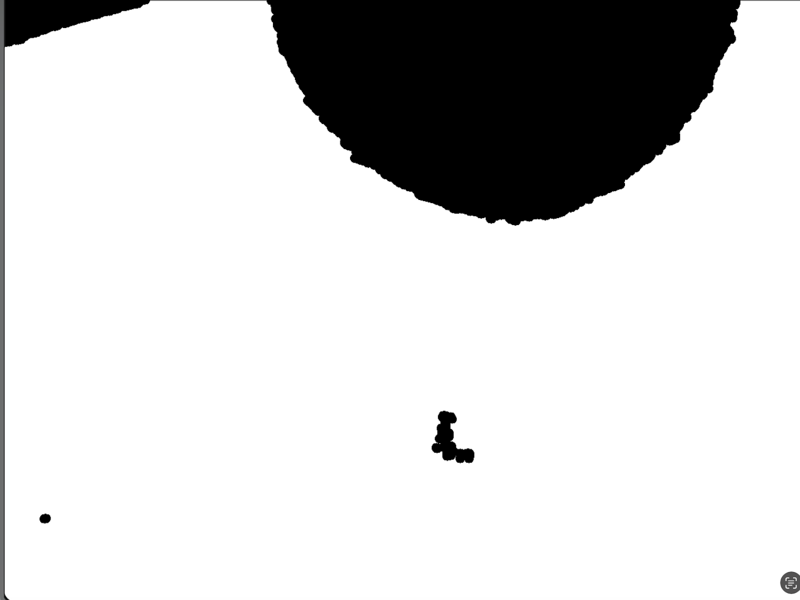
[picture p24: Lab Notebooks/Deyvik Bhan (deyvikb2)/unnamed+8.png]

# **04-19-2025 : Testing OpenCV algorithm**

To evaluate the effectiveness of this approach, I conducted 100 test trials using a range of images. These tests allowed us to assess the consistency of the detection method and better understand its strengths and limitations under varying conditions.

# **04-23-2025 : Attempting to Solder Second PCB**

While assembling our second PCB, we unfortunately damaged the microcontroller. Its small size and fine-pitch pins made it extremely difficult to solder by hand, and we were ultimately unable to attach it properly. Since we didn’t have a replacement microcontroller on hand—and with final demos coming up soon—there’s a strong chance we won’t receive a new one in time. Because of this, we’ve decided to shift our focus to ensuring the entire system works reliably on the development board. This will allow us to still present a fully functional project, even if the second PCB isn’t operational by the time of the demo.

# **2025-04-25 : Final Demo Preparation**

Our group now has the final project fully functioning on the development board, with successful interaction between subsystems—each component is able to trigger others as intended. We’re now shifting our focus to rehearsing for the final demo to ensure we clearly demonstrate both the overall end-to-end functionality and the verification of individual subsystems. To simulate a freezing environment, we’re using a cooler filled with ice. While this setup doesn’t create a perfect 0°C condition, we’ve adjusted our testing by setting 20°C as our freezing threshold. This allows us to demonstrate system behavior under controlled, repeatable conditions.

# 

# **04-30-2025 : Final Presentation Preparation**

Our final demo was a success—we were able to demonstrate full end-to-end functionality with all major subsystems working as intended. The microcontroller generated PWM signals to control the servo motor, and the MOSFET circuit successfully toggled the heater on and off based on control signals. The temperature sensor provided accurate and consistent readings, confirming that it was functioning as expected. For the computer subsystem, we used OpenCV to display a live video feed from the camera and run our raindrop detection algorithm. The system was able to identify visual obstructions, effectively simulating how it would detect raindrops in real-world conditions. We also confirmed that the LED indicator correctly lit up to signal when the heater was active, providing clear visual feedback.

With the demo behind us, we’ve now shifted our attention to the final presentation. I’ve been practicing my portion to clearly explain the motivation, design process, and technical contributions. I’m also fine-tuning my slides to ensure they highlight how each subsystem worked together and how we successfully met our project goals.

# **05-07-2025 : Completion**

Our group just finished the final paper, completing the project. I was responsible for the Requirements and Verification portion for both the individual subsystems and the high level requirements. I also imported all the experiments/data required to demonstrate verification for all the requirements.

# **6 References<u></u>**

[1] 	A. B. Author, “Let it snow: Winter testing for cars, robots, and drones,” Areaxo, [Online]. 
Available:https://areaxo.com. [Accessed: Feb. 12, 2025].

[2] 	Automated Vehicles and Adverse Weather Final Report, Battelle, U.S. Department of 
Transportation Office of the Assistant Secretary for Research and Technology, Federal Highway Administration, FHWA-JPO-19-755, June 2019. [Online]. Available: www.its.dot.gov/index.htm. [Accessed: Feb. 12, 2025].

[3] 	IEEE, “IEEE Code of Ethics,” IEEE Corporate Governance, [Online]. Available: 
https://www.ieee.org/about/corporate/governance/p7-8.html. [Accessed: Feb. 12, 2025].

[4] 	ACM, “ACM Code of Ethics,” ACM, [Online]. Available: 
https://www.acm.org/code-of-ethics. [Accessed: Feb. 12, 2025].

[5] 	IEEE, “IEEE Citation Guidelines,” IEEE Dataport, [Online]. Available: https://ieee-dataport.org/ 
sites/default/files/analysis/27/IEEE%20Citation%20Guidelines.pdf. [Accessed: Feb. 12, 2025].

[6]	HS-318 Servo-Stock Rotation, “HS-318 Servo-Stock Rotation,” ServoCity®, 2025. 
https://www.servocity.com/hs-318-servo/. [Accessed: Mar. 6, 2025].

[7]	“0.3 MegaPixels USB Camera for Raspberry Pi and NVIDIA Jetson Nano 
SKU:FIT0701.” Available: https://mm.digikey.com/Volume0/opasdata/d220001/medias/docus/ 
2719/FIT0701\_Web.pdf. [Accessed: Mar. 6, 2025].

‌[8]	“Waterproof DS18B20 Digital Temperature Sensor for Arduino.” Accessed: Mar. 06,      
2025. [Online]. Available: https://mm.digikey.com/Volume0/opasdata/d220001/medias/docus/ 3786/DFR0198\_Web.pdf. [Accessed: Mar. 6, 2025].

[9]	“NUCLEO-F401RE - STM32 Nucleo-64 development board with STM32F401RE MCU, 
supports Arduino and ST morpho connectivity - STMicroelectronics,” www.st.com. https://www.st.com/en/evaluation-tools/nucleo-f401re.html. [Accessed: Mar. 6, 2025].

‌[10]	“Heating Pad -5x10cm.” Accessed: Mar. 06, 2025. [Online]. Available: https://mm.digikey.com/ 
Volume0/opasdata/d220001/medias/docus/2511/COM-11288\_Web.pdf. [Accessed: Mar. 6, 2025].

[11]	“STM32F103C8 - STMicroelectronics,” STMicroelectronics, 2019. https://www.st.com/en/ 
microcontrollers-microprocessors/stm32f103c8.html. [Accessed: Mar. 6, 2025].

‌[13]	Engineering IT Shared Services, “:: ECE 445 - Senior Design Laboratory,” Illinois.edu, 
2025. https://courses.grainger.illinois.edu/ece445/wiki/#/stm32\_example/index?id= stm32- example-lora-router. [Accessed: Mar. 6, 2025].

[14]	“Servo Motor Control with STM32 | EASY TUTORIAL | STM32CUBEIDE,”
*Youtube*, uploaded by CircuitGator HQ, 15 January 2025, https://www.youtube.com/watch?v=0aTMuiHVx\_g. [Accessed: Apr. 2, 2025].

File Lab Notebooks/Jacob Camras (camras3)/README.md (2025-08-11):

# 2025-02-11- Proposal
Our group worked together on the proposal for the weather resistant camera idea. Together we came together to split up the project into subsystems with us deciding on seven, the heater, sensor, microcontroller, wiper, power, computer, and camera subsystems. I mainly worked on developing the block diagram, part of system overview and requirements. The inital block diagram is below.



# 2025-02-14- Machine shop initial meeting
Me and another group member brought the diagrams developed from the proposal to the machineshop where we explained how our project function. Greg helped come up with designs utilizing boxes and helped pick out servo motors.

# 2025-02-18- Proposal Review with Professor Fliflet
From the proposal review, Professor Fliflet gave us many ideas on implentation with his many questions such as the the size of the box and where certain elements should be placed. 

# 2025-02-21 - 2025-02-24- Part Research
My group decided to research parts. Through all of the options of servo I decided to pick the HS-318 due to its acessability from the ECE shop and typical sturdiness. It also does not seem to be too hard to code for the function that we desire.


Link for motor https://www.servocity.com/hs-318-servo/

Collectively we decided on utilizing the STM32 Microcontroller due to some members having some past experience with it. We also discovered for what we were doing the humidity sensor was not required. 

# 2025-02-25 Inital PCB design
Utlizing the parts chosen from research my group came together to design the PCB. We generally know how each part needs to connect to the board with for example the motor needing three connectors. At this point we are not too sure how to connect the pins of the microcontroller to most aspects of the board. This design is based on the KiCad assignment. Our design is below.



# 2025-02-27 Second PCB design
Our group met up in office hours to check our inital PCB design. We ended up needing to add a decent amount to the design such as a usb connector for the computer subsystem and heater. We also realized that the intial 5V voltage regulator we had implemented was incorrect. The newer design is below. 



# 2025-02-28 PCB Review
Our group met up for the PCB Review where a TA showed us a design for the STM32 Microcontroller on the website. We also decided to not utilize a heater that needed a USB connection. We decided to use a heater that needed simply power and ground connections. We also realized that in order to have a functioning heater that would turn on with signals from the microcontroller, we needed to convert the 3.3V microcontroller signal to 5V.

# 2025-03-05 Design Document and circuit design
Our group met up to work on the Design Document. While the group worked on some sections togehter, we split up others where I was responsible for part of the design overview and verification tables along with some diagrams. Apart from the design document I worked on the circuit design to convert 3.3V to 5V for the heater and confirmed that it works through testing with a voltmeter. The MOSFET I used is the CD4007UBE Below is the circuit schematic as well as the built circuit.

 

# 2025-03-06 Third PCB Design 
With the changes based on the wiki page that was shown to us from the PCB review as well as the addition of the MOSFET circuit we came to our third interation of the PCB design.



# 2025-03-07 Encoding the Motor
With the heating subsytem needing the least amount of work due to the MOSFET circuit working. We decided to focus on different subsystems where I was in charge of the motor system. When trying to incode the motor for the STM32 development board that we recieved on STM32CUBEIDE, the best I could get was the motor to twitch. Checking with the voltmeter I realized I was failing to generate a proper PWM wave

# 2025-03-08 PWM wave generation and Breadboard Demo Preparation
I decided to focus on generating a proper PWM wave and check it through an oscilliscope on scopy. Using the information on the website about the proper wave along with equations and help from a youtube video I was able to generate a PWM wave with 20ms period and 5% duty cycle. However, the motor is not running despite the PWM wave. Below is the equations used, code for proper duty cycle, and the wave generated. 

  

The group also decided to setup our bread board demo where we will showcase the CNN, PWM wave generation, UART working for the temperature sensor, and the MOSFET circuit for the heater.

# 2025-03-11 Wiring PCB Schematic
We met today on zoom where we needed to finish the PCB wiring for the PCB second round. We worked together to place the components where I ended up wiring the rest of it. Although there are 0 unrouted wires, we do not pass the DRC. 

# 2025-03-12 Office hours
In the afternoon me and a group member met up with our TA where we discussed what was wrong with the PCB schematic. I had to leave an hour into the discussion. After returning and through more discussion, the problem was solved through shrinking the wires, making sure each component was connected to both sides of the board, and shrinking certain components. After, I decided to go to office hours to help with the motor issue. Unfortunately even with the TA's help I could not get the motor working with a possible conclusion being that the motor is broken due to my earlier code. Below is our finished PCB schematic



# 2025-03-14 Machine shop
I went to the machine shop with another group memeber where Greg told us to bring a design based upon a box he gave us next time and that our project would not take long to make so we didn't need to give him anything before Spring Break. 

# 2025-03-25 Soldering
We have begun the solder the first PCB and have verified that the power subsystem is working properly as the voltage regulators output 5V and 3.3V with the MOSFET circuit outputting 5V due to no signal from the microcontroller. 

# 2025-03-31 Machine shop
We have given Greg our design for the box and through a servo tester have figured out that the motor was in fact broken.

# 2025-04-02 MOSFET circuit issues
Although we only tested the MOSFET circuit through a voltmeter, we wanted to see if the heater would run with it. Unfortunately the heater is not running and I believe it is a current issue. Thus I decided to use a simpler MOSFET circuit with the IRLZ44N MOSFET. I tested this circuit through LT-SPICE where it gives enough power to the heater. The results from LT-SPICE are below(used sine wave to simulate MOSFET turning on and off) along with the diagram.

  

# 2025-04-03 Second Round PCB
Through figuring out what was wrong with our intial PCB design such as the MOSFET circuit, temperature sensor, etc we are starting to design our final PCB.

# 2025-04-08 - 2025-04-10 Subsystem tests
We bought a test motor and the code works with it. With some fine tuning for the specific window size and wiping motion which require the final build to return from the machine shop, the wiper system will be finished. The MOSFET parts also arrived and I was able to build the circuit on the breadboard and test that it properly works with the heater. The built circuit is below.



# 2025-04-20 - 2025-04-25 Demo Setup
With recieving our final product and the fourth round PCBs not coming in yet, we decided to focus on getting all subsystems working on the Dev board. We also focused on how we would show each subsytem and in what order with us starting with showing the motor and OpenCv systems working properly using a dropper and putting the temperature sensor of the Dev board into the cooler to show that the heater will turn on at the correct time. Below is images of our Dev board setup.

   

# 2025-04-23 Soldering issues
The fourth round of PCBs arrived and while soldering the only microcontroller we had broke. This leaves us in a difficult situation. Although we ordered another, we will now focus on getting the Dev board fully functional as there is not a lot of time left before the final demo.

# 2025-04-30 Final Demo Result and Final Presentation
Although we were unable to get the PCB functioning in time, the Dev board worked perfectly and was showcased well in the Final Demo. We are now preparing for the final presentation where I primarly focused on the description of our inital design, schematics, changes, and our successes, challenges, and failures slides.

# 2025-05-06 Final Paper
We spoke confidently throughout the Final Presentation and did the best we could. For the Final paper the group decided to split it up where I was mainly focused on the Design aspect of it. Overall this project has been a joy to work on and my group had great communication and dilligence. 

# References

[1] 	A. B. Author, “Let it snow: Winter testing for cars, robots, and drones,” Areaxo, [Online]. 
Available:https://areaxo.com. [Accessed: Feb. 12, 2025].
 
[2] 	Automated Vehicles and Adverse Weather Final Report, Battelle, U.S. Department of 
Transportation Office of the Assistant Secretary for Research and Technology, Federal Highway Administration, FHWA-JPO-19-755, June 2019. [Online]. Available: www.its.dot.gov/index.htm. [Accessed: Feb. 12, 2025].

[3] 	IEEE, “IEEE Code of Ethics,” IEEE Corporate Governance, [Online]. Available: 
https://www.ieee.org/about/corporate/governance/p7-8.html. [Accessed: Feb. 12, 2025].
 
[4] 	ACM, “ACM Code of Ethics,” ACM, [Online]. Available: 
https://www.acm.org/code-of-ethics. [Accessed: Feb. 12, 2025].
 
[5] 	IEEE, “IEEE Citation Guidelines,” IEEE Dataport, [Online]. Available: https://ieee-dataport.org/ 
sites/default/files/analysis/27/IEEE%20Citation%20Guidelines.pdf. [Accessed: Feb. 12, 2025].
 
[6]	HS-318 Servo-Stock Rotation, “HS-318 Servo-Stock Rotation,” ServoCity®, 2025. 
https://www.servocity.com/hs-318-servo/. [Accessed: Mar. 6, 2025].
 
[7]	“0.3 MegaPixels USB Camera for Raspberry Pi and NVIDIA Jetson Nano 
SKU:FIT0701.” Available: https://mm.digikey.com/Volume0/opasdata/d220001/medias/docus/ 
2719/FIT0701_Web.pdf. [Accessed: Mar. 6, 2025].
 
‌[8]	“Waterproof DS18B20 Digital Temperature Sensor for Arduino.” Accessed: Mar. 06,      
2025. [Online]. Available: https://mm.digikey.com/Volume0/opasdata/d220001/medias/docus/ 3786/DFR0198_Web.pdf. [Accessed: Mar. 6, 2025].
 
[9]	“NUCLEO-F401RE - STM32 Nucleo-64 development board with STM32F401RE MCU, 
supports Arduino and ST morpho connectivity - STMicroelectronics,” www.st.com. https://www.st.com/en/evaluation-tools/nucleo-f401re.html. [Accessed: Mar. 6, 2025].
 
‌[10]	“Heating Pad -5x10cm.” Accessed: Mar. 06, 2025. [Online]. Available: https://mm.digikey.com/ 
Volume0/opasdata/d220001/medias/docus/2511/COM-11288_Web.pdf. [Accessed: Mar. 6, 2025].
 
[11]	“STM32F103C8 - STMicroelectronics,” STMicroelectronics, 2019. https://www.st.com/en/ 
microcontrollers-microprocessors/stm32f103c8.html. [Accessed: Mar. 6, 2025].
 
‌[13]	Engineering IT Shared Services, “:: ECE 445 - Senior Design Laboratory,” Illinois.edu, 
2025. https://courses.grainger.illinois.edu/ece445/wiki/#/stm32_example/index?id= stm32- example-lora-router. [Accessed: Mar. 6, 2025].
 
[14]	“Servo Motor Control with STM32 | EASY TUTORIAL | STM32CUBEIDE,”
Youtube, uploaded by CircuitGator HQ, 15 January 2025, https://www.youtube.com/watch?v=0aTMuiHVx_g. [Accessed: Apr. 2, 2025].

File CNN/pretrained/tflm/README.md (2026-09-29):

# On-MCU inference (TensorFlow Lite Micro on STM32F4)

The distilled int8 raindrop student runs on the microcontroller. No PC in
the loop: the MCU captures the frame, classifies each 48 px tile, and
triggers the wiper itself. The heater path is unchanged from `main.c`.

## Files

| File | Role |
|---|---|
| `raindrop_inference.cc/.h` | TFLM setup (6-op resolver, 48 KB arena), tile quantization, coverage loop, DWT cycle timer |
| `camera_dcmi.c/.h` | OV7670 over DCMI + DMA, QQVGA RGB565 snapshot, RGB888 conversion |
| `main_raindrop.c` | The firmware main: temperature -> heater, capture -> CNN -> wiper, status over USART2 |
| `raindrop_student_int8.cc/.h` | Generated by `python -m pretrained.to_tflite ... --name raindrop_student` |

## Build (STM32CubeIDE)

1. In `Final.ioc` enable DCMI (8-bit, snapshot), a DMA2 stream for DCMI,
   I2C1, and a 12-24 MHz MCO or PWM output for the camera XCLK. Regenerate.
2. Add `tflite-micro` as a source folder. The easy way: run
   `python tensorflow/lite/micro/tools/project_generation/create_tflm_tree.py -e hello_world /path/to/tflm_tree`
   in a tflite-micro checkout, then import `tflm_tree/` into the project.
   Set the language to C++17 for those files, add `-DTF_LITE_STATIC_MEMORY
   -DTF_LITE_MCU_DEBUG_LOG -DCMSIS_NN` and include `tflm_tree/`,
   `tflm_tree/third_party/flatbuffers/include`, `third_party/gemmlowp`,
   `third_party/kissfft`, `third_party/ruy`.
3. Copy this folder and the generated `raindrop_student_int8.cc/.h` into
   `Core/Src` / `Core/Inc`. Exclude the original `main.c` from the build and
   use `main_raindrop.c`.
4. Link with `-lm`, `-specs=nano.specs -u _printf_float` so the status line
   prints floats.

## Memory

| Buffer | Bytes |
|---|---|
| RGB565 DMA frame 160x120 | 38,400 |
| RGB888 frame | 57,600 |
| TFLM tensor arena | 49,152 |
| Model in flash | `g_raindrop_student_len` (about 25 KB at width 1.0) |

Total SRAM about 150 KB of the F4's 192 KB. If it does not fit alongside
the HAL and stack, drop the RGB888 buffer and convert per tile, or use
`--width 0.5` for the student. `MicroInterpreter::arena_used_bytes()` after
`AllocateTensors()` reports the true arena need; shrink `kArenaBytes` to it.

## Recording the numbers

Every status line prints `nn_us`, the DWT cycle-counter time for the
six-tile pass, and `cover`, the fraction of raindrop tiles. Log USART2 with
`screen /dev/tty.usbmodem* 115200` during a test and average `nn_us` for
the latency figure. Accuracy comes from comparing the printed `grid` against
what you see on the lens per frame.

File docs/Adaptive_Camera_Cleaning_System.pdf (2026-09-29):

# Adaptive Camera Cleaning System

A plain-language walkthrough of what it is, what I built, and how every part works, written to re-learn the project from scratch. UIUC ECE 445 senior design, Jan to May 2025, team of three. Repo: github.com/dbhan08/Weather-Resistant-Camera

## 1. The one-paragraph version

Cameras outdoors get rain and frost on the lens and go blind. We built a box that fixes that by itself. Inside is a tiny computer chip (an STM32 microcontroller) with three jobs. It looks at the lens with a small camera and runs a neural network to decide if there is water on it. If there is, it moves a wiper across the lens with a servo motor. Separately, it reads a temperature sensor and turns on a heating pad when it gets cold, to melt frost. No laptop, no person. Plug it in and it looks after itself.
The one thing to remember: the whole product is a loop that runs once a second on the chip: read temperature, grab a picture, ask the neural network 'is the lens wet?', and move the wiper or switch the heater based on the answers.
Result | Value
Detection accuracy on our 100-image test set | 89 %
When the wiper fires | 5 % or more of the picture is classed as water
When the heater fires | temperature below the threshold (20.5 C in the demo)
Outdoor test | 2 hours continuous
Size of the neural network on the chip | about 20,000 numbers, stored as 8-bit integers

## 2. What I personally did

Three people. The project was split into seven pieces: heater, temperature sensor, microcontroller, wiper, power, camera, and vision (the software that decides if the lens is wet). I owned the last two and the glue between them and the chip.
- Camera. Picked the camera modules, got a live picture out of them, and wrote the code that pulls a frame into the chip's memory.
- Vision. Wrote the rain detector. First a quick hand-tuned version for bring-up, then the real one: a neural network that I built from a published model, adapted to our lens, shrank to fit the chip, and got running on the chip.
- Integration. Wrote the main loop that ties temperature, camera, neural network, wiper and heater together, plus the serial-cable protocol we used during development and the logging used to score the test set.
- Writing. Introduction, Problem Statement and Proposed Solution in the proposal and design doc. The Requirements and Verification section of the final paper, with all the test data.
- Shared. Circuit board layout, machine-shop visits for the enclosure, soldering.

## 3. The parts, and what each one physically does

## 3.1 The microcontroller (STM32F4)

A microcontroller is a whole small computer on one chip: processor, memory, and a set of built-in helper circuits called peripherals. Ours is an STM32F4 made by ST. It has 512 KB of flash (permanent storage where the program and the neural network live) and 192 KB of SRAM (working memory that is wiped at power-off). Those two numbers drove almost every design decision: the neural network and one camera frame both had to fit in 192 KB, together.
The peripherals we use, each explained where it comes up: a timer for the servo, an ADC for the temperature sensor, a UART for the serial cable, an I2C bus and a DCMI port for the camera, and a DMA engine to move camera data without the processor.
We designed our own circuit board for it in KiCad. The final demo ran the same program on a Nucleo, which is ST's ready-made board with the same chip, because we destroyed the chip on our second board while hand-soldering it. The chip's pins are 0.5 mm apart, and a hot iron on that pitch is unforgiving.

## 3.2 The wiper: a servo on a PWM timer

A servo is a small motor that goes to an angle you ask for and holds it. You tell it the angle with a pulse: send a short electrical pulse every 20 milliseconds, and the width of the pulse is the angle. About 1 ms means one end, about 2 ms means the other end. This kind of signal is called PWM, pulse width modulation.
The chip's timer peripheral (TIM2) makes that signal for us. We set it up once so that one full 20 ms period equals some number of timer ticks, and then we just write a 'compare' value that says how many ticks the pulse should stay high. Bigger compare value, wider pulse, bigger angle. The two ends of our servo came out at 210 ticks and 1050 ticks, so the code maps 0 to 180 degrees onto that range with one line of arithmetic:

void Set_Servo_Angle(TIM_HandleTypeDef *htim, uint32_t ch, uint8_t angle) {
uint32_t pulse = 210 + (angle * (1050 - 210) / 180); | // degrees -> ticks
__HAL_TIM_SET_COMPARE(htim, ch, pulse); | // timer does the rest
}
A wipe is a sweep from 60 degrees to 115 and back, moving 3 degrees every 100 ms. Small steps with a pause make the arm move smoothly instead of slamming into the housing. The whole sweep takes about 3.7 s.

for (uint8_t a = 60; a <= 115; a += 3) { Set_Servo_Angle(&htim2, TIM_CHANNEL_1, a); HAL_Delay(100); }
for (uint8_t a = 115; a > 60; a -= 3) { Set_Servo_Angle(&htim2, TIM_CHANNEL_1, a); HAL_Delay(100); }

## 3.3 The temperature sensor: an ADC reading

The STM32 has a temperature sensor built into the silicon. It outputs a voltage that rises with temperature. To read a voltage in software you need an ADC, an analog-to-digital converter, which turns a voltage into a number. Ours is 12-bit, so it gives a number from 0 to 4095.
To turn that number into degrees you need two known points. ST measures every chip at the factory at 30 C and 110 C and burns the two ADC readings into a fixed spot in memory. So the conversion is a straight line through those two points. We also found our readings ran 9 C high against a real thermometer, so we subtract 9.
#define TS_CAL1 (*((uint16_t*)0x1FFF7A2C)) | // factory ADC reading at 30 C

#define TS_CAL2 (*((uint16_t*)0x1FFF7A2E)) | // factory ADC reading at 110 C

extern ADC_HandleTypeDef hadc1; | // ADC1, set up by CubeMX

static float ReadTemperatureC(void) {
HAL_ADC_Start(&hadc1);
HAL_ADC_PollForConversion(&hadc1, HAL_MAX_DELAY); // wait for the conversion

uint32_t raw = HAL_ADC_GetValue(&hadc1); | // 0..4095
HAL_ADC_Stop(&hadc1);
float t = ((float)raw - TS_CAL1) * (110.0f - 30.0f)
/ ((float)TS_CAL2 - TS_CAL1) + 30.0f;
return t - 9.0f; | // offset found against a thermometer
}

## 3.4 The heater: a MOSFET switch on one pin

The heating pad needs more current than a chip pin can supply, and it runs at 5 V while the chip runs at 3.3 V. So the chip does not power the heater. It flips a switch. The switch is a MOSFET, a transistor that lets current flow between two of its legs when a voltage is put on the third leg (the gate). Between the chip and the gate sits a level shifter, a small part that turns the chip's 3.3 V signal into the 5 V the gate wants.
Our wiring is inverted: the pad is on when pin PA5 is low. Pulling the pin low removes the voltage that was keeping the MOSFET off. An LED next to it lights when the heater is on so you can see the state.
#define HEATER_THRESH_C 20.5f | // demo value; 1-2 C in the field

float temp_c = ReadTemperatureC();
// PA5 low = heater ON (the MOSFET is wired inverted)
HAL_GPIO_WritePin(GPIOA, GPIO_PIN_5, temp_c < HEATER_THRESH_C ? GPIO_PIN_RESET : GPIO_PIN_SET);
The threshold is 20.5 C in the demo code, not 0 C. We tested indoors with a cooler of ice, which cools the sensor to the high teens but never to freezing, so we raised the threshold to show the behaviour. In the field you set it to 1 or 2 C.
Design rule: the heater only ever listens to the temperature sensor. The camera and neural network never touch it. Lots of things look like frost in a picture. Temperature is unambiguous.

## 3.5 Power

One 5 V regulator feeds the servo and the heater. A 3.3 V regulator feeds the chip. A regulator is a part that takes a messy input voltage and gives a steady fixed output. We verified both rails with a meter before soldering anything else, so a power fault could not be confused for a code bug later.

## 3.6 The serial cable (UART) for development and logging

A UART sends bytes one at a time down two wires. The chip's USART2 runs at 115200 bits per second and shows up as a serial port on a laptop. During development the laptop sent the word START to run the wiper. In the final product the cable is optional: the chip prints one status line per second on it, and that log is how we scored the test set.

## 4. The camera: getting a picture into the chip

The camera is an OV7670, a fingernail-sized sensor that costs a few dollars. It does not send JPEG files. It streams raw pixels, one after another, on eight data wires, with a clock wire that ticks once per pixel and two more wires that say 'new row' and 'new frame'. Reading that with the processor would eat all its time, so the STM32 has a peripheral for it, DCMI (digital camera interface). DCMI grabs each pixel as it arrives and hands it to DMA, a memory-copy engine that writes into SRAM with no processor involved. The processor starts the capture, goes off to do other work, and gets told when the frame is done.
Before any of that, the camera has to be configured. It has a few dozen internal settings registers written over a two-wire bus called SCCB, which is the same as I2C, a standard two-wire chip-to-chip bus. The settings we write: reset, colour mode, output format, and 'shrink the picture by 4 in each direction'.

static const uint8_t k_ov7670_init[][2] = {
{0x12, 0x80}, // reset
{0x12, 0x14}, // colour (RGB) mode
{0x40, 0xD0}, // RGB565 pixel format
{0x0C, 0x04}, // enable the down-scaler
{0x72, 0x22}, // shrink by 4 in x and y -> 160 x 120 {0x13, 0xE7}, // auto gain, auto white balance, auto exposure
};
extern I2C_HandleTypeDef hi2c1; | // I2C1, set up by CubeMX
#define OV7670_ADDR 0x42 | // the camera's bus address

static int sccb_write(uint8_t reg, uint8_t val) {
uint8_t buf[2] = {reg, val};
return HAL_I2C_Master_Transmit(&hi2c1, OV7670_ADDR, buf, 2, 100) == HAL_OK; }
int CameraInit(void) {
for (i = 0; i < N_INIT_REGS; ++i)
if (!sccb_write(k_ov7670_init[i][0], k_ov7670_init[i][1])) return 0; return 1;
}

## 4.1 Why 160 by 120 and what RGB565 means

The camera can do 640 by 480, but that frame would be 600 KB, three times all our SRAM. We shrink to 160 by 120. Each pixel comes as RGB565: 16 bits per pixel, with 5 bits of red, 6 of green, 5 of blue. That is 38 KB for a frame. The neural network wants normal 8-bit-per-colour pixels (RGB888), so after capture we expand each pixel from 16 bits to 24. The trick in the expansion is to copy the top bits into the empty bottom bits so that full white comes out as 255, not 248.

#define CAM_W 160

#define CAM_H 120

extern DCMI_HandleTypeDef hdcmi; | // DCMI + DMA, set up by CubeMX
static uint16_t s_frame565[CAM_W * CAM_H]; | // 38 KB, DMA writes here
static volatile int s_frame_done; | // set by the interrupt below

void HAL_DCMI_FrameEventCallback(DCMI_HandleTypeDef* h) { s_frame_done = 1; }

int CameraCaptureRGB888(uint8_t* rgb888) { | // rgb888: CAM_W*CAM_H*3 bytes, 58 KB
s_frame_done = 0;
HAL_DCMI_Start_DMA(&hdcmi, DCMI_MODE_SNAPSHOT, (uint32_t)s_frame565, (CAM_W*CAM_H*2)/4); uint32_t t0 = HAL_GetTick();
while (!s_frame_done)
if (HAL_GetTick() - t0 > 500) return 0; | // no frame in 0.5 s: camera unplugged
HAL_DCMI_Stop(&hdcmi);
for (int i = 0; i < CAM_W * CAM_H; ++i) {
uint16_t p = s_frame565[i]; | // one RGB565 pixel

uint8_t r5 = (p >> 11) & 0x1F, g6 = (p >> 5) & 0x3F, b5 = p & 0x1F;
rgb888[3*i+0] = (r5 << 3) | (r5 >> 2); | // 5 bits -> 8 bits
rgb888[3*i+1] = (g6 << 2) | (g6 >> 4); | // 6 bits -> 8 bits
rgb888[3*i+2] = (b5 << 3) | (b5 >> 2);
}
return 1;
}
Memory so far: 38 KB raw frame plus 58 KB expanded frame. That leaves room for the 48 KB the neural network needs, and the rest for the program's own variables and stack.

## 5. The vision: how the chip decides the lens is wet

## 5.1 The idea: cut the picture into tiles and grade each tile

We do not try to outline each drop. We cut the 160 by 120 picture into a grid of 48 by 48 pixel squares, a 3-wide by 2-high grid of six tiles, and ask one question per tile: 'water, or clean?' The fraction of tiles that say water is the coverage. Two of six tiles wet is 33 percent coverage. The wiper fires at 5 percent or more, which for a 6-tile grid means any single tile.
This is a known approach from self-driving-car cameras (Valeo's SoilingNet papers), where it is called a coverage metric. It is cheap enough to run on a microcontroller because the network looks at one small tile at a time, and the grid also tells you where on the lens the water is.

## 5.2 What a neural network is, in this context

A convolutional neural network (CNN) is a function that takes an image in and gives a score per class out. Inside it is a stack of layers. Each layer slides small filters across the image and produces a new, smaller image of 'features': edges first, then blobs, then things like 'a bright ring with a dark edge', which is what a water drop looks like. The numbers in the filters are the weights, and training means adjusting the weights until the scores are right on thousands of labelled example tiles. Once trained, running the network is just multiplications and additions, which a microcontroller can do.

## 5.3 Step 1: start from a published model instead of from zero

Training from zero needs thousands of hand-labelled pictures of our lens, which we did not have. So I started from a model somebody had already trained on rain: Breckon's group at Durham published a small network in 2018 that looks at 30 by 30 patches from a car windshield camera and says drop or no drop, with 95 percent accuracy. They released the trained weights under an MIT licence.
Problem: the weights were saved in TensorFlow 1 with a library called TFLearn, both of which are dead. Nothing modern can load them. But the file is just a list of named arrays of numbers, and TensorFlow 2 can still read the raw arrays. So I rebuilt the same network layer by layer in Keras (the modern TensorFlow API) and copied each array into the matching layer by name, checking every shape:

# port_breckon.py

# Keras layer name -> name of the same layer inside the old TF1 checkpoint _NAME_MAP = {"conv1": "Conv2D", "conv2": "Conv2D_1", "conv3": "Conv2D_2",

"conv4": "Conv2D_3", "conv5": "Conv2D_4",
"fc1": "FullyConnected", "fc2": "FullyConnected_1", "fc3": "FullyConnected_2"}
def load_tfl_weights(model, tfl_path): | # model: the Keras copy; tfl_path: the .tfl file
reader = tf.train.load_checkpoint(tfl_path) | # opens the old TF1 file
for keras_name, ckpt_name in _NAME_MAP.items():
layer = model.get_layer(keras_name)

w = reader.get_tensor(f"{ckpt_name}/W") | # weights array
b = reader.get_tensor(f"{ckpt_name}/b") | # bias array
assert w.shape == layer.get_weights()[0].shape | # fail loudly if the port is wrong
layer.set_weights([w, b])
model = build_alexnet30() | # same layers, random weights
load_tfl_weights(model, "models/alexnet_30_2_classification.tfl") model.save("runs/breckon/alexnet30_2.keras")
The network itself: five convolution layers (96 filters of 11x11, then 256 of 5x5, then 384, 384 and 256 of 3x3), with pooling layers between that shrink the image, then two dense layers of 4096 numbers each, then a 2-way output. To check the port, I ran the 16 sample patches that ship with their code and compared the answers.

## 5.4 Step 2: adapt it to our lens (fine-tuning)

Their camera looked through a windshield a metre away. Ours is millimetres from the drops, so our drops are huge and blurry by comparison. A model trained on one does worse on the other. The fix is fine-tuning: keep the trained weights, then train a little more on pictures like ours so it adjusts.
For pictures like ours I used a public dataset, RaindropsOnWindshield: 8,190 frames where every drop has been outlined by hand (a mask), free to use with credit. A script cuts it into 30 by 30 patches. A patch counts as 'water' if at least 30 percent of it is inside a drop outline. It counts as 'clean' only if the patch and a one-patch border around it have no drop at all, so a drop edge never sneaks into a 'clean' example and confuses the training. Frames from our own camera were added the same way. The split into training and test sets is by video clip, so the test never contains frames from a clip the model trained on, which would inflate the score.

# data_windshield.py -- cut labelled 30x30 patches from one frame and its mask

PATCH = 30
img = np.asarray(Image.open(frame_path).convert("RGB")) | # H x W x 3, the photo
mask = np.asarray(Image.open(mask_path).convert("L")) > 127 | # H x W, True where a drop is
pos, neg = [], [] | # patches we keep

# positive: centred on a random drop pixel, mask covers >= 30 % of the patch

ys, xs = np.nonzero(mask) | # coordinates of all drop pixels
k = rng.randrange(len(ys))
y0, x0 = ys[k] - PATCH // 2, xs[k] - PATCH // 2
if mask[y0:y0+PATCH, x0:x0+PATCH].mean() >= 0.30:
pos.append(img[y0:y0+PATCH, x0:x0+PATCH])

# negative: random spot where the patch PLUS a one-patch border has no drop at all y0, x0 = rng.randrange(0, H - PATCH), rng.randrange(0, W - PATCH)

border = mask[max(0, y0-PATCH):y0+2*PATCH, max(0, x0-PATCH):x0+2*PATCH]
if border.max() == 0:
neg.append(img[y0:y0+PATCH, x0:x0+PATCH])

# split by video clip, not by frame (sequences = list of clip folder names) rng.shuffle(sequences); n = len(sequences)

train, val, test = sequences[:int(.7*n)], sequences[int(.7*n):int(.85*n)], sequences[int(.85*n):] # patches are saved to data/patches/{train,val,test}/{raindrop,non_raindrop}/*.png
The fine-tuning itself is the standard recipe. First freeze the convolution layers and train only the dense layers at the end at a normal learning rate for a few rounds. Then unfreeze everything and train at a tiny learning rate, stopping as soon as the score on held-out data stops improving. Each training image is randomly flipped and rotated up to 45 degrees so the model does not memorise orientation.

# finetune.py

model = keras.models.load_model("runs/breckon/alexnet30_2.keras") # the ported network

def make_ds(folder, training): | # folder = data/patches/train, val or test
ds = keras.utils.image_dataset_from_directory(
folder, label_mode="categorical", class_names=["non_raindrop", "raindrop"], image_size=(30, 30), batch_size=64)
aug = keras.Sequential([RandomFlip("horizontal_and_vertical"),
RandomRotation(0.125), | # +-45 degrees
RandomBrightness(0.15), RandomContrast(0.15)]) return ds.map(lambda x, y: (aug(x / 255.0) if training else x / 255.0, y)) train_ds = make_ds("data/patches/train", True)
val_ds = make_ds("data/patches/val", False)
test_ds = make_ds("data/patches/test", False)

# stage 1: only the dense head learns

for layer in model.layers:
layer.trainable = layer.name.startswith("fc") model.compile(keras.optimizers.Adam(1e-3), "categorical_crossentropy", metrics=["accuracy"]) model.fit(train_ds, validation_data=val_ds, epochs=5)

# stage 2: everything learns, very gently, stop when validation stops improving

for layer in model.layers:
layer.trainable = True
model.compile(keras.optimizers.Adam(1e-5), "categorical_crossentropy", metrics=["accuracy"]) model.fit(train_ds, validation_data=val_ds, epochs=10,
callbacks=[EarlyStopping(patience=3, restore_best_weights=True)])
test = model.evaluate(test_ds, return_dict=True) | # accuracy, written to finetune_report.json
model.save("runs/breckon_ft/alexnet30_2_ft.keras") | # this is the teacher for the next step

## 5.5 Step 3: shrink it 900 times (distillation)

Here is the wall. Count the weights: those two dense layers are 256 by 4096 and 4096 by 4096. Together with the rest that is about 18 million numbers. In 4-byte floats that is 75 MB. Even squeezed to 1 byte each it is 19 MB. Our chip has 512 KB of flash. The big model cannot go on the chip, full stop. It also uses one layer type (local response normalization) that the chip-side library does not support.
So the big model does not go on the chip. It becomes the teacher. I designed a tiny student network that does fit, and trained the student to copy the teacher. This is knowledge distillation. Instead of only telling the student 'this tile is water', you show it the teacher's full opinion, like '80 percent water, 20 percent clean'. Those soft answers carry much more information per example, including what the teacher learned about hard cases like glare, which is exactly where our first detector failed.
The student: input is a 48 by 48 tile. A first small convolution, then five 'depthwise separable' blocks, a MobileNet trick that does a cheap per-channel filter followed by a cheap 1x1 mixing filter instead of one expensive full filter, which cuts the maths by about 8 times. Then average everything down to one vector and a final layer that outputs two scores. About 20,000 weights total. Every layer type is one the chip-side library supports.

# distill_student.py

def ds_block(x, channels, stride): | # one depthwise-separable block
x = DepthwiseConv2D(3, strides=stride, padding="same")(x) | # cheap per-channel 3x3
x = ReLU()(BatchNormalization()(x))
x = Conv2D(channels, 1)(x) | # cheap 1x1 mixing
return ReLU()(BatchNormalization()(x))

def build_student():
inp = Input((48, 48, 3)) | # one tile, pixels scaled 0..1
x = Conv2D(16, 3, strides=2, padding="same")(inp) | # 48x48 -> 24x24
x = ds_block(x, 32, 2); x = ds_block(x, 32, 1) | # -> 12x12
x = ds_block(x, 64, 2); x = ds_block(x, 64, 1) | # -> 6x6
x = ds_block(x, 128, 2) | # -> 3x3
x = GlobalAveragePooling2D()(x) | # 3x3x128 -> 128 numbers

return Model(inp, Dense(2)(x)) | # 2 raw scores: clean, water

teacher = keras.models.load_model("runs/breckon_ft/alexnet30_2_ft.keras")
teacher.trainable = False | # the teacher never changes
student = build_student()
T, alpha = 4.0, 0.7 | # temperature, weight on the teacher term
def train_step(x, y): | # x: batch of 48x48 tiles, y: one-hot true labels
p_teacher = teacher(tf.image.resize(x, (30, 30))) | # teacher's probabilities
p_teacher = p_teacher ** (1 / T) | # soften at temperature T
p_teacher /= tf.reduce_sum(p_teacher, 1, keepdims=True) | # renormalise
with tf.GradientTape() as tape:
logits = student(x, training=True)
p_student = tf.nn.softmax(logits / T) | # softened the same way
loss = alpha * KL(p_teacher, p_student) * T**2 + (1 - alpha) * CrossEntropy(y, logits) grads = tape.gradient(loss, student.trainable_variables) # only the student learns optimizer.apply_gradients(zip(grads, student.trainable_variables))

# run train_step over data/patches/train for up to 30 epochs, early-stop on val accuracy, then: student.save("runs/student/student.keras")

## 5.6 Step 4: turn floats into 8-bit integers (quantization)

Trained weights are 32-bit floating point numbers. Microcontrollers are slow at floating point and flash is small, so we convert the whole network to 8-bit integers. Each weight becomes a number from -128 to 127 plus one shared scale factor per layer that says what one step is worth. Same for the numbers flowing between layers at run time. That is 4 times smaller and several times faster, and on a network this size it costs almost no accuracy.
To pick the scale factors for the run-time numbers, the converter needs to see typical inputs. You hand it a 'representative dataset', a few hundred real tiles, and it runs them through and records how big each layer's numbers get. I use tiles from the validation set, not the training set, so the scales are not tuned to the exact images the weights were fitted on. The output is a .tflite file, plus that file dumped as a C array so it compiles straight into the firmware.

# to_tflite.py

student = keras.models.load_model("runs/student/student.keras") val_tiles = load_patches("data/patches/val", side=48, limit=300)
# val_tiles: numpy array, 300 x 48 x 48 x 3, pixel values 0..1

conv = tf.lite.TFLiteConverter.from_keras_model(student)
conv.optimizations = [tf.lite.Optimize.DEFAULT] | # turn on quantization
conv.representative_dataset = lambda: (([x[None]],) for x in val_tiles) | # 300 tiles, one at a time
conv.target_spec.supported_ops = [tf.lite.OpsSet.TFLITE_BUILTINS_INT8] | # int8 kernels only
conv.inference_input_type = conv.inference_output_type = tf.int8 | # int8 in, int8 out
model_bytes = conv.convert() | # the whole .tflite file as
bytes
open("raindrop_student_int8.tflite", "wb").write(model_bytes)

# write_c_array(): the same bytes as a normal C source file

body = ",".join(f"0x{b:02x}" for b in model_bytes) | # "0x1c,0x00,0x00,..."
open("raindrop_student_int8.cc", "w").write(
f"alignas(16) const unsigned char g_raindrop_student[] = {{{body}}};\n"
f"const unsigned int g_raindrop_student_len = {len(model_bytes)};\n") open("raindrop_student_int8.h", "w").write(
"extern const unsigned char g_raindrop_student[];\n"
"extern const unsigned int g_raindrop_student_len;\n")
How that array ends up in flash: on a microcontroller, anything declared const is placed by the linker in the read-only data section, and that section lives in the flash address range. So compiling raindrop_student_int8.cc into the firmware and flashing the board puts the weights in flash with the rest of the program. No copying code is needed. At run time TensorFlow Lite Micro reads the model straight from that address (tflite::GetModel(g_raindrop_student) returns a pointer, not a copy), so the weights never take up any SRAM. Only the 48 KB working arena does. The alignas(16) is there because the library reads the model with 16-byte aligned loads.

## 5.7 Step 5: run it on the chip (TensorFlow Lite Micro)

TensorFlow Lite Micro (TFLM) is a small C++ library that runs .tflite models on microcontrollers with no operating system and no dynamic memory. You give it the model bytes, a list of which layer types to compile in (we register only the six we use, to save flash), and a fixed block of memory called the arena where it keeps all the intermediate results. Ours is 48 KB. At boot:

// raindrop_inference.cc
#include "raindrop_student_int8.h" | // g_raindrop_student[] from to_tflite.py

constexpr int kArenaBytes = 48 * 1024;
alignas(16) uint8_t g_arena[kArenaBytes]; | // working memory for all layer outputs
tflite::MicroMutableOpResolver<6> g_resolver; | // which layer types to compile in
tflite::MicroInterpreter* g_interp;
TfLiteTensor *g_in, *g_out; | // the model's input and output tensors

int RaindropInit(void) {
const tflite::Model* model = tflite::GetModel(g_raindrop_student); // flash pointer, no copy g_resolver.AddConv2D(); g_resolver.AddDepthwiseConv2D(); g_resolver.AddMean(); g_resolver.AddFullyConnected(); g_resolver.AddReshape(); g_resolver.AddSoftmax();
static tflite::MicroInterpreter interp(model, g_resolver, g_arena, kArenaBytes);
g_interp = &interp;
if (g_interp->AllocateTensors() != kTfLiteOk) return 0; // carve up the arena once g_in = g_interp->input(0); g_out = g_interp->output(0);
return g_in->type == kTfLiteInt8 && g_in->dims->data[1] == 48; // sanity check
}
Per frame, the code walks the 3 by 2 grid. For each tile it copies the 48 rows out of the big frame into a small buffer, converts each pixel byte into the network's int8 input using the scale and zero-point that the converter stored inside the model, runs the network, and reads the two output scores. Whichever score is bigger wins; there is no need to convert back to real probabilities, because the comparison works directly on the integers.

#define TILE 48

// rgb: one tile, TILE*TILE*3 bytes. Returns 1 if the network says "raindrop".
static int ClassifyTile(const uint8_t* rgb) {
float scale = g_in->params.scale; | // stored in the model by the converter
int | zp | = g_in->params.zero_point;
for (int i = 0; i < TILE * TILE * 3; ++i) {
// trained on pixel/255, so: q = round((pixel/255) / scale) + zero_point
int q = (int)(rgb[i] / (255.0f * scale) + 0.5f) + zp; g_in->data.int8[i] = (int8_t)(q < -128 ? -128 : q > 127 ? 127 : q);
}
g_interp->Invoke(); | // run the six layers
return g_out->data.int8[1] > g_out->data.int8[0]; // index 1 = raindrop
}

// frame: the RGB888 picture from CameraCaptureRGB888. Returns fraction of tiles that are wet. float RaindropCoverage(const uint8_t* frame, int width, int height, uint8_t* grid_out) { static uint8_t tile[TILE * TILE * 3];
int rows = height / TILE, cols = width / TILE, hits = 0; // 120/48 = 2, 160/48 = 3
for (int r = 0; r < rows; ++r)
for (int c = 0; c < cols; ++c) {
for (int y = 0; y < TILE; ++y) | // copy 48 rows of 48 pixels out of the frame
| | memcpy(tile + y*TILE*3, frame + ((r*TILE + y)*width + c*TILE)*3, TILE*3);

int wet = ClassifyTile(tile);

hits += wet;
if (grid_out) grid_out[r*cols + c] = wet; // per-tile map for the log }
return (float)hits / (rows * cols); | // coverage, 0.0 to 1.0
}
A hardware cycle counter inside the processor (the DWT) times each pass. The count is printed on the status line, which is where our per-frame timing numbers came from.

## 6. Putting it together: the main loop

Everything above is called from one loop that runs once per second. Read it top to bottom and you have the whole product.

#define HEATER_THRESH_C | 20.5f | // heater on below this

#define WIPE_THRESHOLD | 0.05f | // 5 % of tiles wet -> wipe

#define WIPE_COOLDOWN_MS 4000u | // one sweep takes ~3.7 s

#define LOOP_PERIOD_MS | 1000u

static uint8_t s_frame[CAM_W * CAM_H * 3]; | // 58 KB RGB888 picture
static uint8_t s_grid[6]; | | // 3 x 2 tile results
uint32_t last_wipe = 0;
int cam_ok = CameraInit(), nn_ok = RaindropInit();

for (;;) {
uint32_t t0 = HAL_GetTick(); | // milliseconds since boot

// 1. temperature -> heater
float temp_c = ReadTemperatureC();
int heat = temp_c < HEATER_THRESH_C;
HAL_GPIO_WritePin(GPIOA, GPIO_PIN_5, heat ? GPIO_PIN_RESET : GPIO_PIN_SET);

// 2-3. picture -> neural network -> coverage
float cover = -1.0f;
if (cam_ok && nn_ok && CameraCaptureRGB888(s_frame))
cover = RaindropCoverage(s_frame, CAM_W, CAM_H, s_grid);

// 4. coverage -> wiper, with two safety rules
if (cover >= WIPE_THRESHOLD && temp_c > 0.0f
&& HAL_GetTick() - last_wipe > WIPE_COOLDOWN_MS) { Wipe();
last_wipe = HAL_GetTick();
}

// 5. one line of log per second
printf("T=%.1fC heat=%d cover=%.2f grid=%d%d%d%d%d%d nn_us=%lu\r\n", temp_c, heat, cover, s_grid[0], s_grid[1], s_grid[2], s_grid[3], s_grid[4], s_grid[5], RaindropLastInferenceUs()); HAL_Delay(LOOP_PERIOD_MS - (HAL_GetTick() - t0));
}
The two safety rules on the wiper: it never runs at or below 0 C, because a wiper dragging over ice strips the blade and stalls the servo, and it never runs again within 4 seconds, because one sweep takes 3.7 seconds and the next frame would still see the wet lens mid-wipe and fire again.
If the camera or the model fails to start, the loop keeps running the heater and prints the failure. During development it could also fall back to the laptop sending START over the cable.

## 6.1 Where the memory goes

Buffer | Size | Why
Raw RGB565 camera frame | 38 KB | DMA writes here
Expanded RGB888 frame | 58 KB | what the network reads
TFLM arena | 48 KB | all intermediate layer outputs
Model (in flash, not SRAM) | about 25 KB | the int8 weights
Total SRAM | about 150 KB of 192 KB | rest is stack and HAL state

## 6.2 Building it

In STM32CubeIDE, turn on DCMI, a DMA stream for it, I2C1, and a clock output for the camera in the .ioc file and let CubeMX generate the setup code. Pull the TensorFlow Lite Micro sources in as a folder (there is a script in their repo, create_tflm_tree.py, that produces exactly the files you need) and compile them as C++17. Add the three firmware files and the generated model array. Swap the old main.c for main_raindrop.c. Flash and open the serial port.

## 7. How we got here: the earlier detector and what it taught us

The first detector was not a neural network. It was a quick OpenCV pipeline on the laptop, written to get something moving. OpenCV is a standard image library. The idea: water on glass looks grey, so convert the picture to HSV (hue, saturation, value: colour, how colourful, how bright), keep pixels that are not colourful (saturation under 40) and not dark (value over 100), fill the little gaps to make solid blobs, draw circles around the biggest blobs, and count what fraction of the picture is inside them. Over 5 percent, send START down the cable.

# final_code.py (development version, ran on the laptop)

frame = cv2.flip(cap.read()[1], 0) | # camera is mounted upside down
h, s, v = cv2.split(cv2.cvtColor(frame, cv2.COLOR_BGR2HSV)) | # hue, saturation, value channels
kernel = cv2.getStructuringElement(cv2.MORPH_ELLIPSE, (15, 15))
_, s_mask = cv2.threshold(s, 40, 255, cv2.THRESH_BINARY_INV) | # low saturation
_, v_mask = cv2.threshold(v, 100, 255, cv2.THRESH_BINARY) | # not dark
closed = cv2.morphologyEx(cv2.bitwise_and(s_mask, v_mask), cv2.MORPH_CLOSE, kernel) contours = sorted(cv2.findContours(closed, ...)[0], key=cv2.contourArea, reverse=True)
for c in contours[1:3]: | # skip the biggest (lens ring), fill the next two
(x, y), r = cv2.minEnclosingCircle(c)
cv2.circle(closed, (int(x), int(y)), int(r), 0, -1) # fill it black
black_percent = 100 * np.sum(closed == 0) / closed.size
if black_percent > 5: ser.write(b"START") # ser = serial.Serial("COM3", 115200)
It worked on clean test pictures and failed in the enclosure: glare, scratches and surface texture all got flagged as water. Our TA found the real reason by looking at the hardware, not the code: the camera is so close to the surface where drops form that it is effectively zoomed way in, and tiny texture becomes big blobs. No threshold fixes that. You need something that has learned what a drop looks like versus what glare looks like. That is the whole reason for the neural network path, and why distillation from a teacher that had seen lots of glare mattered.
The 5 percent rule survived from the heuristic into the final product. Everything else was replaced.

## 8. How we tested it

- Detection accuracy: 89 percent. 100 test images of rain and ice on the lens in different lighting. For each, the chip's printed tile grid was compared with what was actually on the lens.
- Each part alone first. Regulators on a meter (5 V and 3.3 V). MOSFET output with and without gate drive. Servo on a servo tester at the machine shop, which is how we found one motor was simply dead. Temperature against a real thermometer, which gave us the 9 C offset. PWM on a scope.
- The model pipeline. Every stage writes a report file: did every weight array match on the port, how did the sample patches score, test accuracy after fine-tuning, student test accuracy after distillation, and how often int8 agrees with the float model after quantization. A separate PyTorch pipeline in the repo (lens_soiling/) has nine automated tests as a fallback.

- Everything together. Final demo with all subsystems triggering each other: an ice cooler and the 20.5 C threshold for the heater, water on the lens for the wiper, LED confirming heater state. Then two hours outdoors.

## 9. What went wrong and what we did

Problem | Why | What we did
First detector flagged glare as water | Lens millimetres from the wet surface magnifies texture | Replaced it with a learned tile classifier; distilled from a teacher that had seen glare
Published model far too big for the chip | 18 M weights; uses a layer TFLM lacks | Kept it as the teacher; distilled a 20 k-weight student
Published weights would not load | Saved by dead TF1 / TFLearn | Read the raw arrays, rebuilt the network in Keras, copied by name
Frame plus model did not fit memory | 192 KB SRAM | 160x120 frames, 48 KB arena, only six layer types compiled in
Second PCB's chip destroyed | 0.5 mm pin pitch, hand soldering | Ran the same firmware on the Nucleo dev board
Servo would not move | Dead motor | Proved it on a servo tester, replaced it
Could not test freezing indoors | Ice cooler tops out around 15 C | Raised the heater threshold to 20.5 C for the demo

## 10. If someone asks

- Why tiles instead of finding each drop? Cheaper by far, fits a microcontroller, and the wipe decision only needs 'how much', not 'what shape'.
- Why not train your own small model from scratch? No big labelled dataset of our lens. The teacher had already learned rain and glare from thousands of images; distillation moves that into the student for free.
- Why does the heater ignore the camera? Frost, fog, and dirt look alike. Temperature does not lie.
- Hardest bug? The glare false positives. The fix came from looking at the mechanical setup, not the code.
- What would you change? Mount the camera further from the wet surface. Add a frost class to the student. Use an STM32H7 with more memory for a full-size frame and a bigger student.

References: Guo, Akcay, Adey, Breckon, ICIP 2018 (github.com/tobybreckon/raindrop-detection-cnn). Soboleva & Shipitko, RaindropsOnWindshield, 2021 (Zenodo 4680442). Uricar et al., SoilingNet, ITSC 2019. Hinton, Vinyals, Dean, Distilling the Knowledge in a Neural Network, 2015. Howard et al., MobileNets, 2017. Code: Weather-Resistant-Camera/CNN/ and main.c.

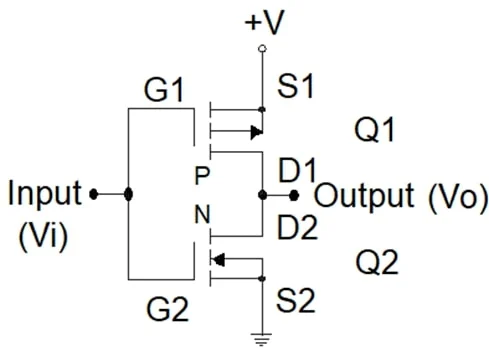
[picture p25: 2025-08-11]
PCB Design/basic-cmos-logic-gates-fig1.webp

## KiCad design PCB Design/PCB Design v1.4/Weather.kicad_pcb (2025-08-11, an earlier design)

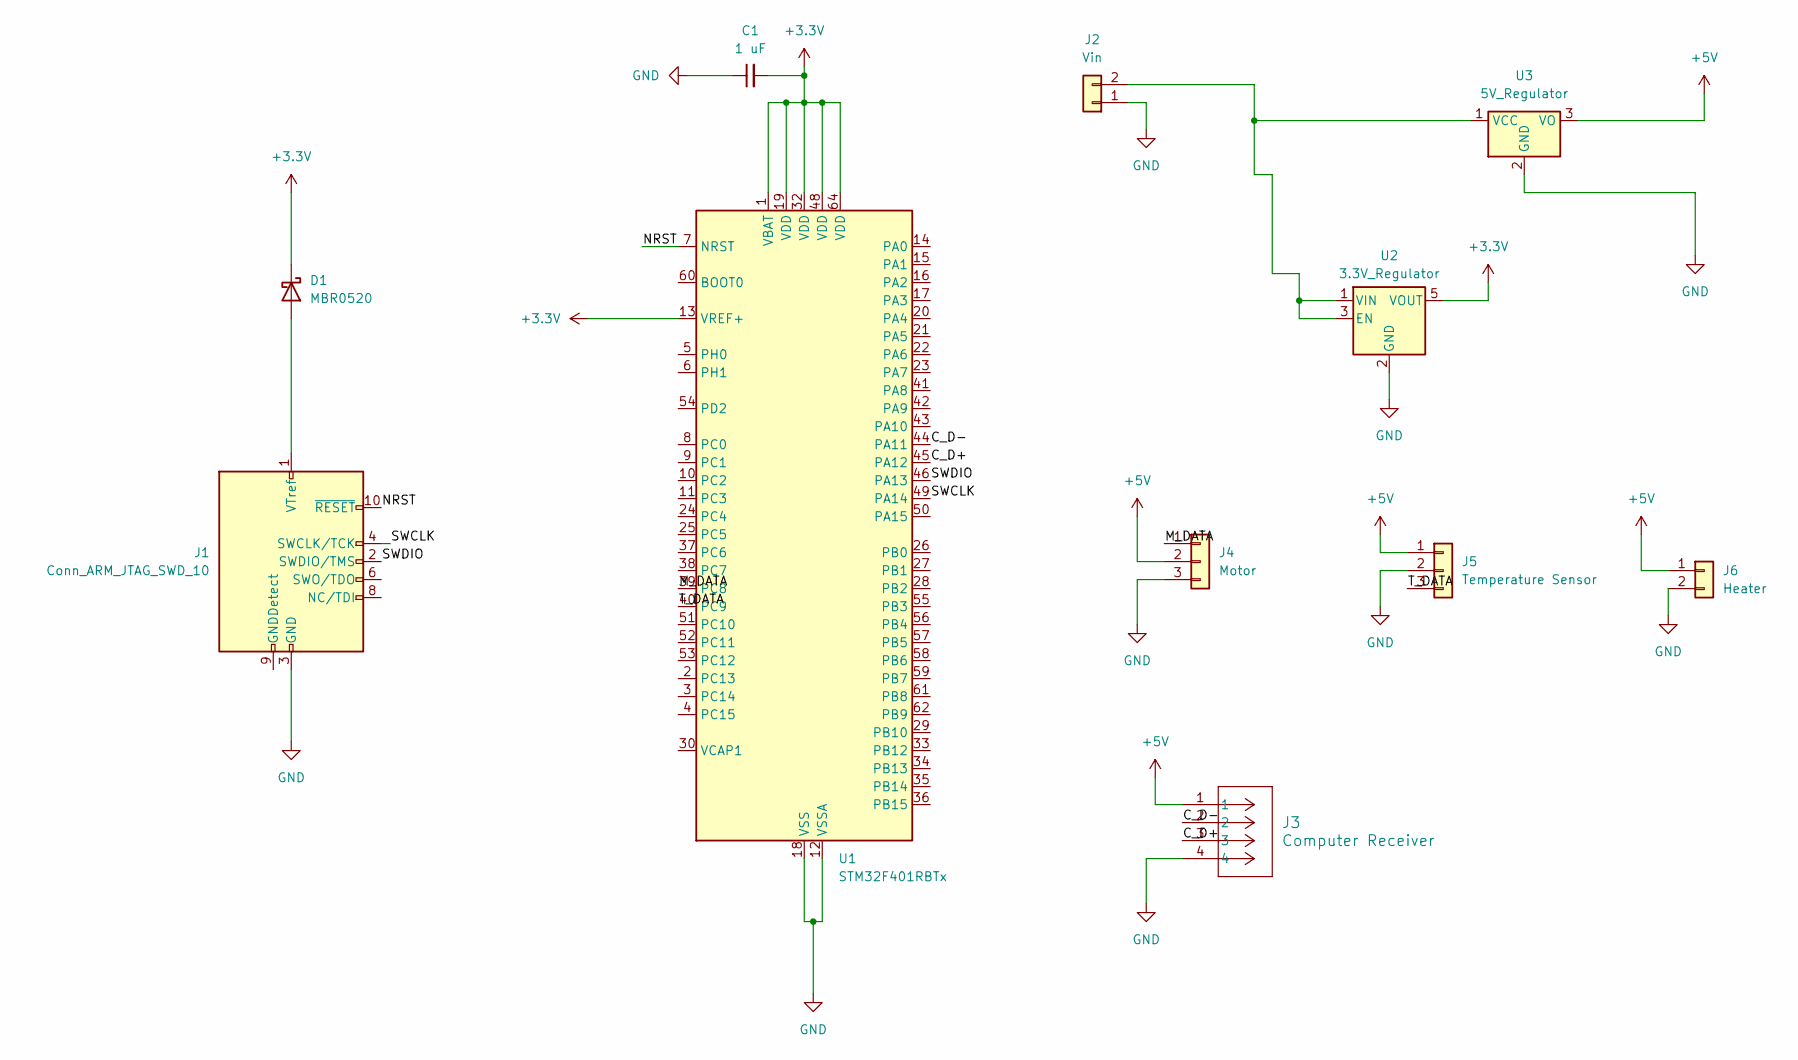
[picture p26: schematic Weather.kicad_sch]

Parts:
C1: 1 uF; C_0805_2012Metric_Pad1.18x1.45mm_HandSolder
D1: MBR0520; D_SOD-123
J1: Conn_ARM_JTAG_SWD_10; PinHeader_2x05_P1.27mm_Vertical
J2: Vin; Molex_KK-254_AE-6410-02A_1x02_P2.54mm_Vertical
J3: Computer Receiver; CONN_USB-AP-S-RA-SMT_ADM
J4: Motor; Molex_KK-254_AE-6410-03A_1x03_P2.54mm_Vertical
J5: Temperature Sensor; Molex_KK-254_AE-6410-03A_1x03_P2.54mm_Vertical
J6: Heater; Molex_KK-254_AE-6410-02A_1x02_P2.54mm_Vertical
U1: STM32F401RBTx; LQFP-64_10x10mm_P0.5mm
U2: 3.3V_Regulator; SOT-23-5_HandSoldering
U3: 5V_Regulator; TO-252-2

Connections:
+3.3V: C1.2, D1.1 (K), U1.1 (VBAT), U1.13 (VREF+), U1.19 (VDD), U1.32 (VDD), U1.48 (VDD), U1.64 (VDD), U2.5 (VOUT)
+5V: J3.1, J4.2, J5.1, J6.1, U3.3 (VO)
/C_D+: J3.3, U1.45 (PA12)
/C_D-: J3.2, U1.44 (PA11)
/M_DATA: J4.1, U1.39 (PC8)
/NRST: J1.10 (~RESET), U1.7 (NRST)
/SWCLK: J1.4 (SWCLK/TCK), U1.49 (PA14)
/SWDIO: J1.2 (SWDIO/TMS), U1.46 (PA13)
/T_DATA: J5.3, U1.40 (PC9)
GND: C1.1, J1.3 (GND), J1.5 (GND), J2.1, J3.4, J4.3, J5.2, J6.2, U1.12 (VSSA), U1.18 (VSS), U1.31 (VSS), U1.47 (VSS), U1.63 (VSS), U2.2 (GND), U3.2 (GND)
unnamed: D1.2 (A), J1.1 (VTref)
unnamed: J2.2, U2.1 (VIN), U2.3 (EN), U3.1 (VCC)

Board: 2 copper layers, 11 parts (0 on the bottom side), 12 nets, no tracks yet.

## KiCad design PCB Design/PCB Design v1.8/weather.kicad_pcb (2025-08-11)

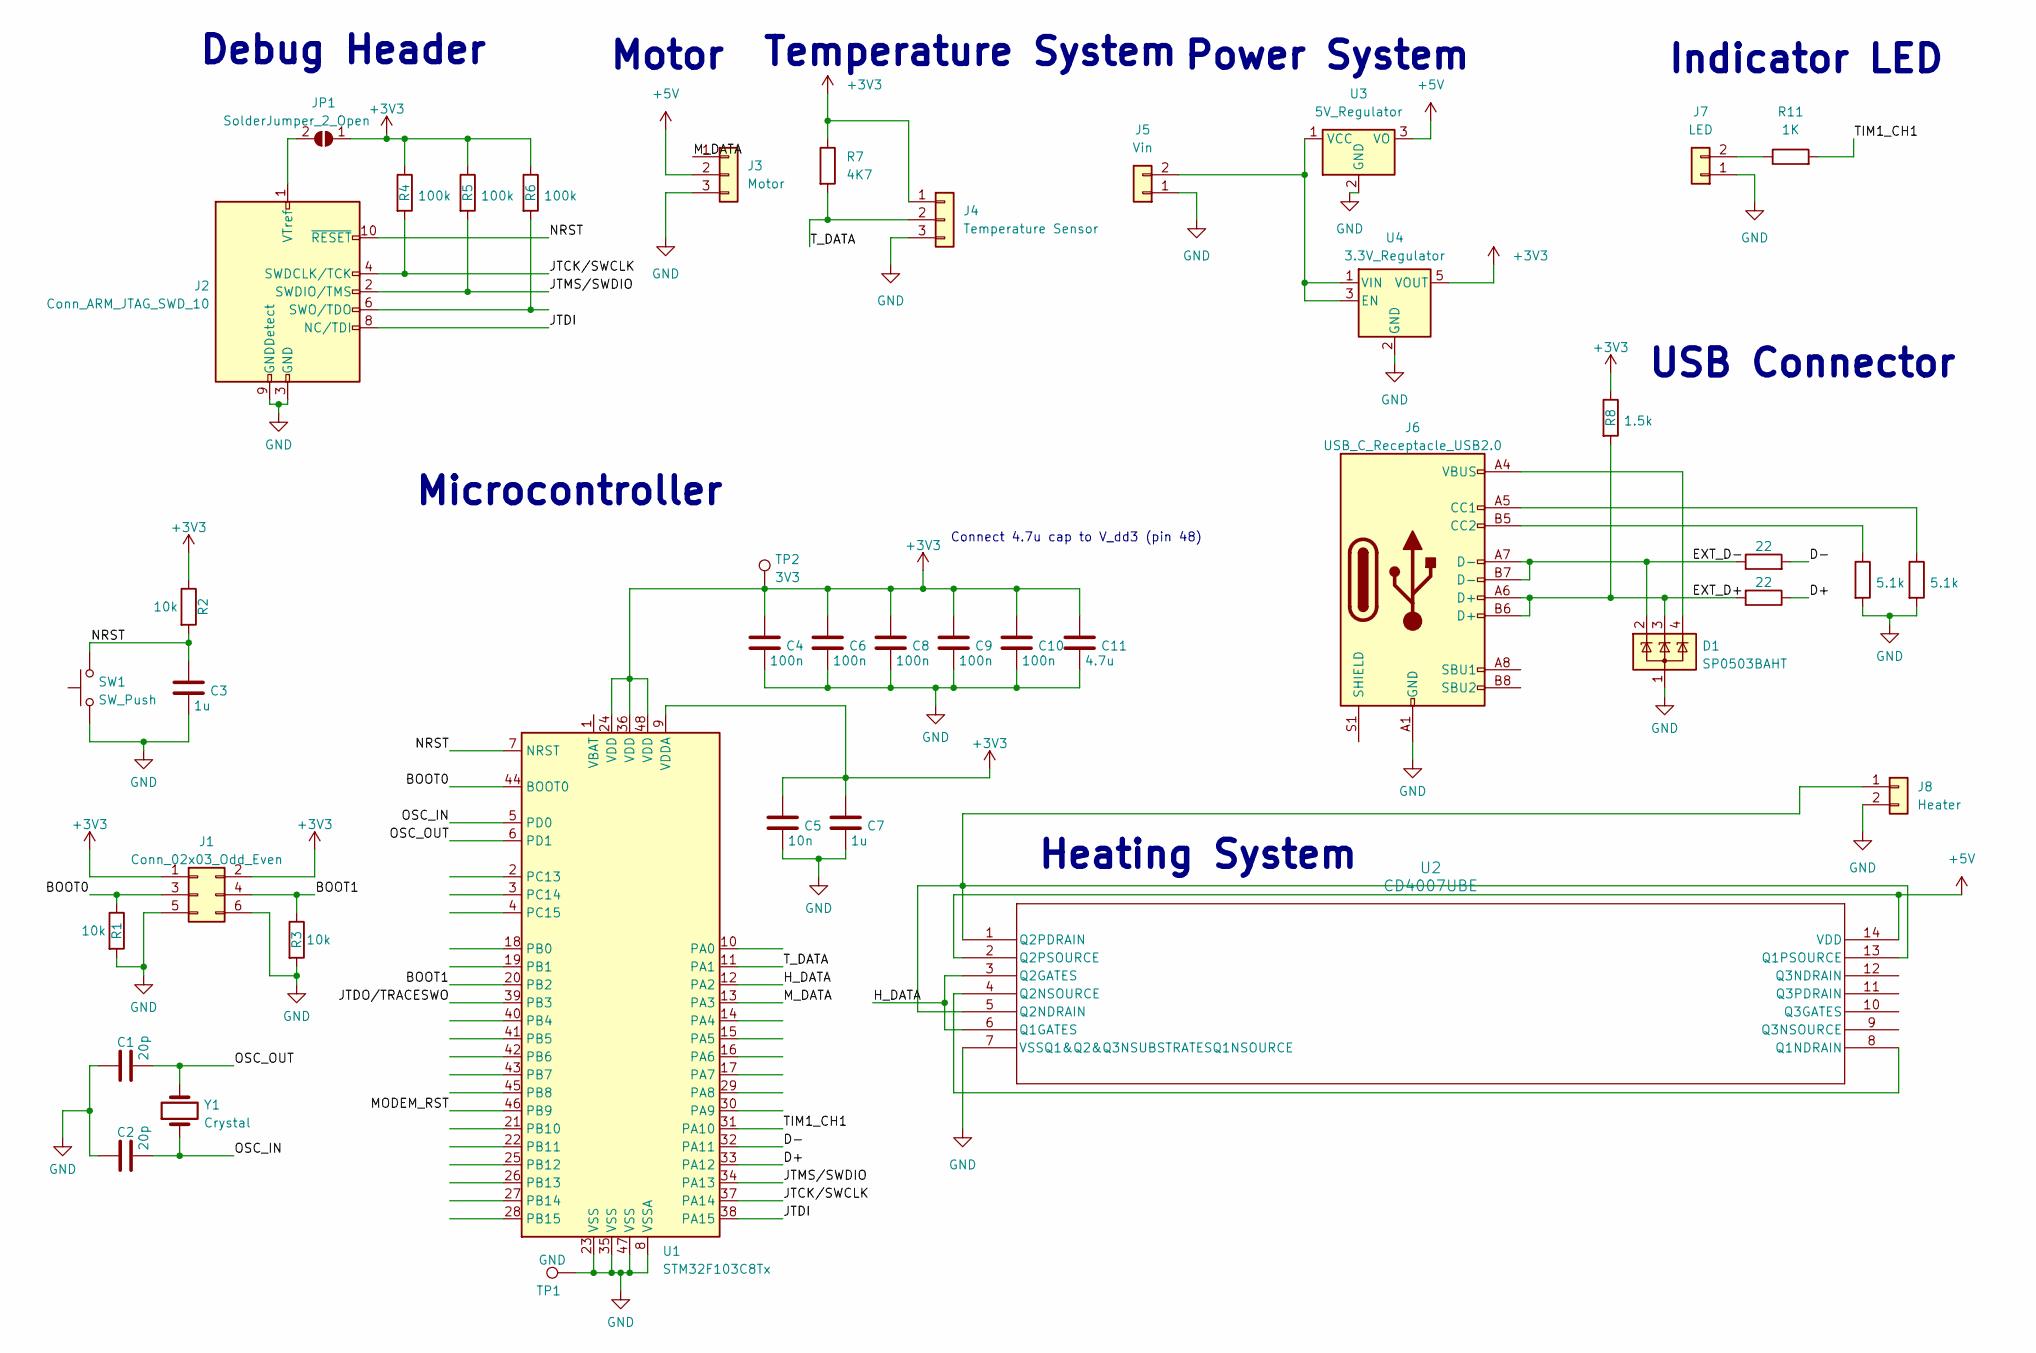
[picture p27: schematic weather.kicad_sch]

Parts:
C1, C2: 20p; C_0603_1608Metric
C3, C7: 1u; C_0603_1608Metric
C4, C6, C8, C9, C10: 100n; C_0603_1608Metric
C5: 10n; C_0603_1608Metric
C11: 4.7u; C_0603_1608Metric
D1: SP0503BAHT; SOT-143
J1: Conn_02x03_Odd_Even; PinSocket_2x03_P2.54mm_Vertical
J2: Conn_ARM_JTAG_SWD_10; IDC-Header_2x05_P2.54mm_Vertical
J3: Motor; Molex_KK-254_AE-6410-03A_1x03_P2.54mm_Vertical
J4: Temperature Sensor; Molex_KK-254_AE-6410-03A_1x03_P2.54mm_Vertical
J5: Vin; Molex_KK-254_AE-6410-02A_1x02_P2.54mm_Vertical
J6: USB_C_Receptacle_USB2.0; USB_C_Receptacle_Amphenol_12401610E4-2A_CircularHoles
J7: LED; Molex_KK-254_AE-6410-02A_1x02_P2.54mm_Vertical
J8: Heater; Molex_KK-254_AE-6410-02A_1x02_P2.54mm_Vertical
JP1: SolderJumper_2_Open; SolderJumper-2_P1.3mm_Open_TrianglePad1.0x1.5mm
R1, R2, R3: 10k; R_0603_1608Metric
R4, R5, R6: 100k; R_0603_1608Metric
R7: 4K7; R_0603_1608Metric
R8: 1.5k; R_0603_1608Metric
R9, R10: 22; R_0603_1608Metric
R11: 1K; R_0603_1608Metric
R12, R13: 5.1k; R_0603_1608Metric
SW1: SW_Push; SW_SPST_B3S-1000
TP1: GND; TestPoint_Keystone_5000-5004_Miniature
TP2: 3V3; TestPoint_Keystone_5000-5004_Miniature
U1: STM32F103C8Tx; LQFP-48_7x7mm_P0.5mm
U2: CD4007UBE; N14
U3: 5V_Regulator; TO-252-2
U4: 3.3V_Regulator; SOT-23-5_HandSoldering
Y1: Crystal; Crystal_HC49-U_Vertical

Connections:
+3V3: C4.1, C5.1, C6.1, C7.1, C8.1, C9.1, C10.1, C11.1, J1.1, J1.2, J4.1, JP1.1 (A), R2.1, R4.1, R5.1, R6.1, R7.1, R8.1, TP2.1, U1.9 (VDDA), U1.24 (VDD), U1.36 (VDD), U1.48 (VDD), U4.5 (VOUT)
+5V: J3.2, U2.2 (Q2PSOURCE), U2.14 (VDD), U3.3 (VO)
/BOOT0: J1.3, R1.1, U1.44 (BOOT0)
/BOOT1: J1.4, R3.1, U1.20 (PB2)
/D+: R10.1, U1.33 (PA12)
/D-: R9.2, U1.32 (PA11)
/EXT_D+: D1.3 (K), J6.A6 (D+), J6.B6 (D+), R8.2, R10.2
/EXT_D-: D1.2 (K), J6.A7 (D-), J6.B7 (D-), R9.1
/H_DATA: U1.12 (PA2), U2.3 (Q2GATES), U2.6 (Q1GATES)
/JTCK/SWCLK: J2.4 (SWDCLK/TCK), R4.2, U1.37 (PA14)
/JTDI: J2.8 (NC/TDI), U1.38 (PA15)
/JTDO/TRACESWO: U1.39 (PB3)
/JTMS/SWDIO: J2.2 (SWDIO/TMS), R5.2, U1.34 (PA13)
/MODEM_RST: U1.46 (PB9)
/M_DATA: J3.1, U1.13 (PA3)
/NRST: C3.1, J2.10 (~RESET), R2.2, SW1.2, U1.7 (NRST)
/OSC_IN: C2.2, U1.5 (PD0), Y1.1
/OSC_OUT: C1.2, U1.6 (PD1), Y1.2
/TIM1_CH1: R11.2, U1.31 (PA10)
/T_DATA: J4.2, R7.2, U1.11 (PA1)
GND: C1.1, C2.1, C3.2, C4.2, C5.2, C6.2, C7.2, C8.2, C9.2, C10.2, C11.2, D1.1 (A), J1.5, J1.6, J2.3 (GND), J2.5 (GND), J2.9 (GNDDetect), J3.3, J4.3, J5.1, J6.A1 (GND), J6.A12 (GND), J6.B1 (GND), J6.B12 (GND), J7.1, J8.2, R1.2, R3.2, R12.2, R13.2, SW1.1, TP1.1, U1.8 (VSSA), U1.23 (VSS), U1.35 (VSS), U1.47 (VSS), U2.7 (VSSQ1&Q2&Q3NSUBSTRATESQ1NSOURCE), U3.2 (GND), U4.2 (GND); also elsewhere on the board
unnamed: D1.4 (K), J6.A4 (VBUS), J6.A9 (VBUS), J6.B4 (VBUS), J6.B9 (VBUS)
unnamed: J2.6 (SWO/TDO), R6.2
unnamed: J2.1 (VTref), JP1.2 (B)
unnamed: J5.2, U3.1 (VCC), U4.1 (VIN), U4.3 (EN)
unnamed 25: J6.A5 (CC1), R13.1; also elsewhere on the board
unnamed 26: J6.B5 (CC2), R12.1; also elsewhere on the board
unnamed: J7.2, R11.1
unnamed: J8.1, U2.1 (Q2PDRAIN), U2.5 (Q2NDRAIN), U2.13 (Q1PSOURCE)
unnamed: U2.4 (Q2NSOURCE), U2.8 (Q1NDRAIN)

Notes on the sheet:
Debug Header
Motor
Microcontroller
USB Connector
Temperature System
Heating System
Indicator LED
Connect 4.7u cap to V_dd3 (pin 48)
Power System

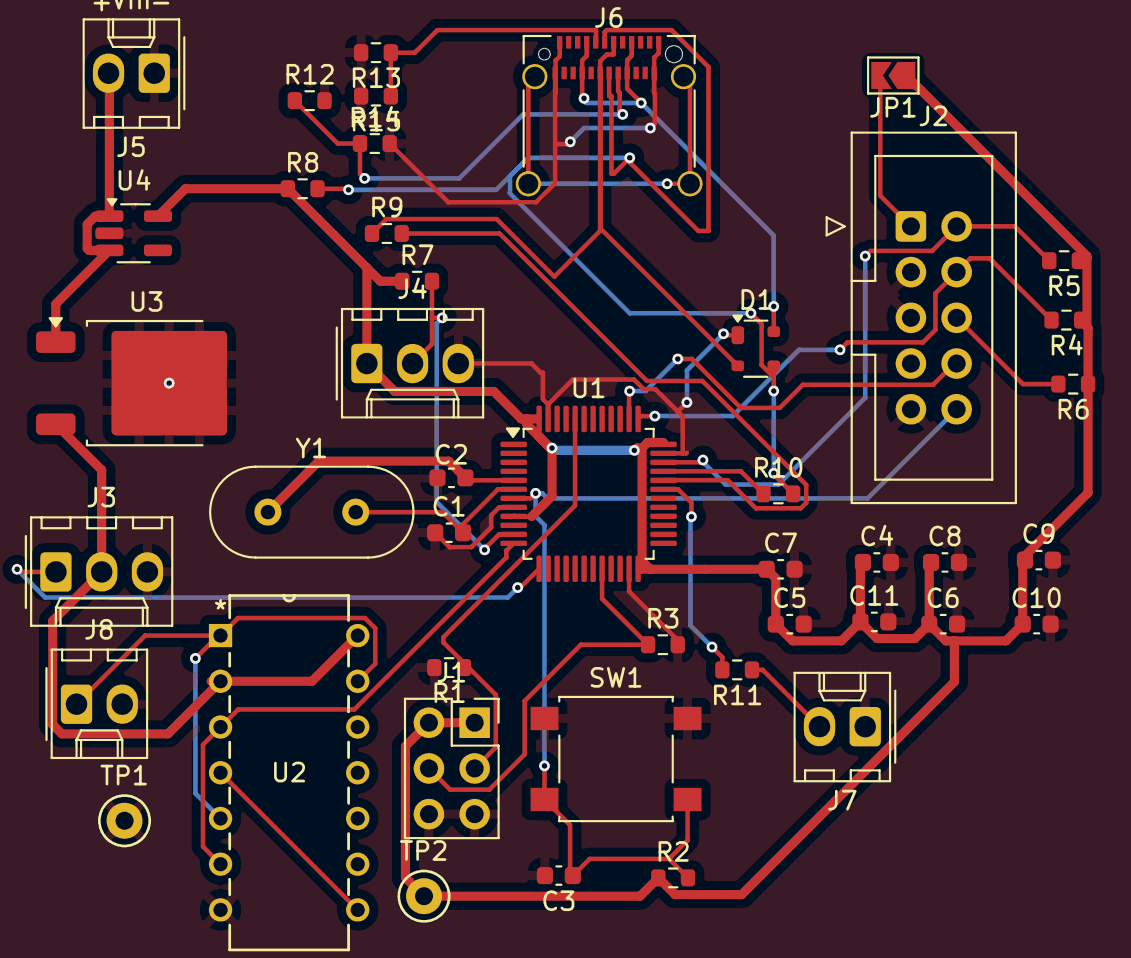
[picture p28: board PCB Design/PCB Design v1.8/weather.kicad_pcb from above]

Board: 2 copper layers, 44 parts (0 on the bottom side), 28 nets.

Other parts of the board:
R14, R15: 5.1k; R_0603_1608Metric

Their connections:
GND: R14.2, R15.2; also elsewhere on the board
unnamed 25: R15.1; also elsewhere on the board
unnamed 26: R14.1; also elsewhere on the board

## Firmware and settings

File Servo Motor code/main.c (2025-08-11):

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
/* Includes ------------------------------------------------------------------*/
#include "main.h"

TIM_HandleTypeDef htim2;

void SystemClock_Config(void);
static void MX_GPIO_Init(void);
static void MX_TIM2_Init(void);
/* USER CODE BEGIN 0 */
void Set_Servo_Angle(TIM_HandleTypeDef *htim,uint32_t channel, uint8_t angle){
	uint32_t pulse_length = 210 + (angle*(1050-210)/180);
	__HAL_TIM_SET_COMPARE(htim,channel, pulse_length);
}
/* USER CODE END 0 */

/**
  * @brief  The application entry point.
  * @retval int
  */
int main(void)
{

  /* MCU Configuration--------------------------------------------------------*/

  /* Reset of all peripherals, Initializes the Flash interface and the Systick. */
  HAL_Init();

  /* Configure the system clock */
  SystemClock_Config();

  /* Initialize all configured peripherals */
  MX_GPIO_Init();
  MX_TIM2_Init();
  /* USER CODE BEGIN 2 */
  HAL_TIM_PWM_Start(&htim2, TIM_CHANNEL_1);
  /* USER CODE END 2 */

  /* Infinite loop */
  /* USER CODE BEGIN WHILE */
  while (1)
  {
    /* USER CODE END WHILE */

    /* USER CODE BEGIN 3 */
	  for (uint8_t angle=0; angle<=180; angle+=10){
		  Set_Servo_Angle(&htim2, TIM_CHANNEL_1,angle);
		  HAL_Delay(100);
	  }
	  for (uint8_t angle=180; angle>0; angle-=10){
	 		  Set_Servo_Angle(&htim2, TIM_CHANNEL_1,angle);
	 		  HAL_Delay(100);
	 	  }
  }
  /* USER CODE END 3 */
}

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


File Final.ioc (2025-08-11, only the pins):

Mcu.UserName=STM32F401RETx
PA0-WKUP.Signal=S_TIM2_CH1_ETR
PA13.Signal=SYS_JTMS-SWDIO
PA14.Signal=SYS_JTCK-SWCLK
PA2.Signal=USART2_TX
PA3.Signal=USART2_RX
PA5.GPIO_Label=Heater
PA5.Signal=GPIO_Output

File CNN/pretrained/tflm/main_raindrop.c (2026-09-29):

/* Weather-Resistant Camera: on-chip rain detection main loop.
 *
 * This is ../../../main.c with the PC removed from the loop.  The heater and
 * servo code is unchanged.  The wiper trigger now comes from the int8
 * raindrop CNN running under TensorFlow Lite Micro on the STM32 instead of a
 * "START" byte string over UART.
 *
 * Per loop iteration (about 4 s when idle, dominated by the capture cadence):
 *   1. read on-die temperature, switch heater MOSFET on PA5 below THRESH_C
 *   2. capture a 160x120 RGB frame over DCMI
 *   3. classify the 3x2 grid of 48 px tiles  -> coverage in [0,1]
 *   4. if coverage >= WIPE_THRESHOLD and temperature > 0 C and the cooldown
 *      has elapsed, sweep the servo 60 -> 115 -> 60 degrees
 *   5. print a one-line status over USART2 for logging on the PC
 *
 * CubeMX (Final.ioc) must have: TIM2 CH1 PWM (servo), ADC1 temp sensor,
 * USART2, DCMI + DMA2 stream, I2C1, plus a 12-24 MHz clock out for XCLK.
 */

#include <stdio.h>
#include <string.h>

#include "main.h"
#include "camera_dcmi.h"
#include "raindrop_inference.h"

/* ---- peripherals generated by CubeMX (declared in main.h / main.c) ---- */
extern ADC_HandleTypeDef hadc1;
extern TIM_HandleTypeDef htim2;
extern UART_HandleTypeDef huart2;
extern void SystemClock_Config(void);
extern void MX_GPIO_Init(void);
extern void MX_ADC1_Init(void);
extern void MX_USART2_UART_Init(void);
extern void MX_TIM2_Init(void);
extern void MX_DCMI_Init(void);
extern void MX_I2C1_Init(void);
extern void MX_DMA_Init(void);

/* ---- tunables ---- */
#define HEATER_THRESH_C   20.5f   /* demo threshold; 0-2 C in the field */
#define WIPE_THRESHOLD    0.05f   /* same 5 % rule as the OpenCV heuristic */
#define WIPE_COOLDOWN_MS  4000u   /* one sweep is ~3.7 s at 100 ms/step */
#define LOOP_PERIOD_MS    1000u

/* ---- factory temperature calibration (STM32F4 reference manual) ---- */
#define TS_CAL1 (*((uint16_t*)0x1FFF7A2C))  /* raw ADC at 30 C  */
#define TS_CAL2 (*((uint16_t*)0x1FFF7A2E))  /* raw ADC at 110 C */

static uint8_t s_frame[CAM_W * CAM_H * 3];
static uint8_t s_grid[(CAM_H / RAINDROP_TILE) * (CAM_W / RAINDROP_TILE)];

int _write(int file, char* ptr, int len) {
  (void)file;
  HAL_UART_Transmit(&huart2, (uint8_t*)ptr, len, HAL_MAX_DELAY);
  return len;
}

void Set_Servo_Angle(TIM_HandleTypeDef* htim, uint32_t channel, uint8_t angle) {
  uint32_t pulse = 210 + (angle * (1050 - 210) / 180);
  __HAL_TIM_SET_COMPARE(htim, channel, pulse);
}

static float ReadTemperatureC(void) {
  HAL_ADC_Start(&hadc1);
  HAL_ADC_PollForConversion(&hadc1, HAL_MAX_DELAY);
  uint32_t raw = HAL_ADC_GetValue(&hadc1);
  HAL_ADC_Stop(&hadc1);
  float t = ((float)raw - TS_CAL1) * (110.0f - 30.0f) / ((float)TS_CAL2 - TS_CAL1) + 30.0f;
  return t - 9.0f; /* manual offset found in testing, as in main.c */
}

static void Wipe(void) {
  for (uint8_t a = 60; a <= 115; a += 3) { Set_Servo_Angle(&htim2, TIM_CHANNEL_1, a); HAL_Delay(100); }
  for (uint8_t a = 115; a > 60; a -= 3)  { Set_Servo_Angle(&htim2, TIM_CHANNEL_1, a); HAL_Delay(100); }
}

int main(void) {
  HAL_Init();
  SystemClock_Config();
  MX_GPIO_Init();
  MX_DMA_Init();
  MX_ADC1_Init();
  MX_USART2_UART_Init();
  MX_TIM2_Init();
  MX_I2C1_Init();
  MX_DCMI_Init();
  HAL_TIM_PWM_Start(&htim2, TIM_CHANNEL_1);
  Set_Servo_Angle(&htim2, TIM_CHANNEL_1, 60);

  const int cam_ok = CameraInit();
  const int nn_ok = RaindropInit();
  printf("camera=%d model=%d\r\n", cam_ok, nn_ok);

  uint32_t last_wipe = 0;
  for (;;) {
    const uint32_t t0 = HAL_GetTick();

    /* 1. heater from the thermistor, unchanged */
    const float temp_c = ReadTemperatureC();
    const int heat = temp_c < HEATER_THRESH_C;
    HAL_GPIO_WritePin(GPIOA, GPIO_PIN_5, heat ? GPIO_PIN_RESET : GPIO_PIN_SET);

    /* 2-3. capture and classify */
    float cover = -1.0f;
    if (cam_ok && nn_ok && CameraCaptureRGB888(s_frame)) {
      cover = RaindropCoverage(s_frame, CAM_W, CAM_H, s_grid);
    }

    /* 4. wipe on coverage; never run the wiper on ice */
    int wiped = 0;
    if (cover >= WIPE_THRESHOLD && temp_c > 0.0f && (HAL_GetTick() - last_wipe) > WIPE_COOLDOWN_MS) {
      Wipe();
      last_wipe = HAL_GetTick();
      wiped = 1;
    }

    /* 5. status line: temperature, heater, coverage, grid, inference time */
    printf("T=%.1fC heat=%d cover=%.2f grid=", temp_c, heat, cover);
    for (unsigned i = 0; i < sizeof s_grid; ++i) printf("%d", s_grid[i]);
    printf(" nn_us=%lu wipe=%d\r\n", (unsigned long)RaindropLastInferenceUs(), wiped);

    const uint32_t spent = HAL_GetTick() - t0;
    if (spent < LOOP_PERIOD_MS) HAL_Delay(LOOP_PERIOD_MS - spent);
  }
}

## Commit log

2025-08-11 Adding Project
    [WRCPCBI1.kicad_sch, Weather.kicad_pcb, Weather.kicad_sch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]
2026-09-29 Add CNN rain detection: pretrained AlexNet-30² port → distill → int8 TFLite Micro, plus tested PyTorch fallback
    - pretrained/: Keras port of Breckon's TF1 raindrop weights, RaindropsOnWindshield
    patch extraction, two-stage fine-tune, knowledge distillation to a 20k-param
    student, full-int8 TFLite conversion with C array, TFLM inference + main.c hook
    - lens_soiling/: synthetic drop/frost renderer, tiny depthwise-separable net,
    int8 export, tile-grid inference driving the existing START serial command
    - tests/: 9 unit + integration tests (train → export → infer) passing
    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
2026-09-29 Rename soil_* to raindrop_*; add full on-MCU firmware: TFLM inference, DCMI camera capture, main loop
    - raindrop_inference.cc/.h: MicroInterpreter setup, per-tile int8 quantization,
    coverage loop, DWT cycle timing
    - camera_dcmi.c/.h: OV7670 QQVGA RGB565 via DCMI+DMA, RGB888 conversion
    - main_raindrop.c: thermistor→heater, capture→CNN→wiper, USART2 status line
    - tflm/README.md: CubeIDE build steps, SRAM budget, how to log metrics
    - README reworded around the deployed on-MCU path
2026-09-29 Add project explainer PDF (system, responsibilities, camera/MCU integration)

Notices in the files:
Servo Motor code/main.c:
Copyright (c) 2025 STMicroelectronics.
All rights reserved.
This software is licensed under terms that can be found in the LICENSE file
